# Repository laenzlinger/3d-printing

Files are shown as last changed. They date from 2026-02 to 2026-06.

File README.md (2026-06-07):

# 3d printing

Documentation for maintaining a Creality Ender 3 V2 Neo with Klipper firmware.

**Documentation:**
- [docs/maintenance.md](docs/maintenance.md) - System information and AI-assisted maintenance guide
- [docs/gitops.md](docs/gitops.md) - GitOps workflow for configuration management
- [docs/petg-guide.md](docs/petg-guide.md) - PETG printing guide and troubleshooting
- [docs/cura-petg-profile.md](docs/cura-petg-profile.md) - Cura profile setup for PETG
- [docs/session-notes.md](docs/session-notes.md) - Print session notes and tuning history

**Quick Commands:**
```bash
make              # Show all available commands
make status       # Check printer status
make sync         # Pull backup and verify
make deploy       # Deploy config to printer
make logs         # View Klipper logs
```

## OrcaSlicer Profiles

Profiles live in `orca-profiles/` and are used by the `make slice` command.

```bash
make profiles                                          # List available profiles
make slice STL=part.stl MATERIAL=PETG PROCESS="PETG Tuned"  # Slice with specific profile
make slice-print STL=part.stl MATERIAL=PETG PROCESS="PETG Strong"  # Slice and start print
```

### Filament Profiles

| Profile | Nozzle | Bed | Fan | Retraction | Use for |
|---|---|-----|-----|---|---|
| PLA | 200°C | 60°C | 40% | 1.5mm @ 30mm/s | General purpose, decorative parts |
| PETG | 235°C | 80°C | 40% | 1.5mm @ 30mm/s | Structural parts, outdoor use |

### Process Profiles

| Profile | Layers | Walls | Infill | Speed | Use for |
|---|---|---|---|---|---|
| PLA Tuned | 0.20mm | 3 (0.45mm) | 15% grid | 125mm/s | Fast PLA prints, non-structural |
| PETG Tuned | 0.20mm | 3 (0.4mm) | 25% gyroid | 50mm/s | Standard PETG, moderate strength |
| PETG Strong | 0.16mm | 4 (0.4mm) | 50% gyroid | 40mm/s | Max strength, functional/structural parts |

All process profiles share: 0.28mm first layer, 140% first layer line width (0.56mm), skirt by default (brim enabled case-by-case), 0.3mm Z-hop.

### Profile Selection Guide

- **Decorative / fast** → PLA + PLA Tuned
- **General PETG** → PETG + PETG Tuned
- **Structural / load-bearing** → PETG + PETG Strong (bike parts, brackets, mounts)

## Git Hooks

Run once after cloning:
```bash
./scripts/setup-git-hooks.sh
```

Pre-commit hooks check:
- Printer config syntax
- Cura profile structure
- No temp files committed

## TODO

- [ ] Extend start gcode purge line (current line is too short for consistent priming)
- [ ] Tune PETG retraction and feed settings (stringing/blob issues)
- [x] ~~Test PLA bed temp 65°C for better adhesion on textured PEI (ESP case warped at 60°C)~~
  - 65°C caused elephant foot, no warping improvement
  - Reducing PLA max fan to 40% fixed warping → applied to all PLA profiles

## Creality Ender 3 V2 Neo

### System Access

* Web Interface: https://3d.laenzlinger.net
* SSH: `ssh 3d.home`

### Mods

* [Filament guide](https://www.printables.com/model/93203-filament-guide-for-ender-3-v2)
* [Bed Leveling Wheel Clips](https://www.printables.com/model/115938-ender-3-bed-leveling-wheel-clips/files)
* [Camera Mount](https://www.printables.com/model/440579-ender-3-v2-neo-mount-for-pi-camera-module-v1-v2/files)
* [Light Bar](https://www.printables.com/model/360416-stealth-light-bar-resized-for-ender-3-pro-v2-neo-v)
* [Raspberry Pi Case](https://www.printables.com/model/106225-modular-snap-together-raspberry-pi-2b3b3b4-case-w-)

### Klipper Setup

The printer runs [Klipper](https://www.klipper3d.org/) firmware installed via [KIAUH](https://github.com/dw-0/kiauh).

Configuration backup is maintained at: https://github.com/laenzlinger/klipper-backup

Hardware:
* Creality 4.2.2 Mainboard
* TJC display

### Legacy Firmware (Pre-Klipper)

Previously used [Professional Firmware](https://github.com/mriscoc/Ender3V2S1) with [custom build for TJC display](https://github.com/mriscoc/Special_Configurations/releases/tag/tjc).

SD card formatting for firmware flashing (4096 byte sector size):

```sh
# Find the SD card
diskutil list

# Format as FAT32 with 4096 byte sector size (e.g., disk4s1)
sudo newfs_msdos -F 32 -b 4096 disk4s1
```

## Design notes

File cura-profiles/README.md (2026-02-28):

# Cura Profile Management

## Profile Structure

Cura 5.x uses two files per profile:
1. `creality_ender3_[NAME].inst.cfg` - Printer-level settings (bed temp, etc.)
2. `creality_base_extruder_0_[NAME].inst.cfg` - Extruder settings (temps, speeds, etc.)

## Installing Profiles

### Method 1: Copy to Cura config (Recommended)
```bash
cp cura-profiles/*.inst.cfg ~/.local/share/cura/5.11/quality_changes/
```

Then restart Cura and the profile will appear in your profiles list.

### Method 2: Import via Cura UI
Cura 5.x doesn't support importing `.inst.cfg` files directly through the UI.
Use Method 1 instead.

## Available Profiles

### PETG Profile
- **Files**: 
  - `creality_ender3_PETG.inst.cfg`
  - `creality_base_extruder_0_PETG.inst.cfg`
- **Settings**: Optimized for PETG at 240°C/80°C
- **Features**: Brim, Z-hop, proper cooling for PETG

### Modcase Profile (Your Current)
- **Files**:
  - `creality_ender3_modcase.inst.cfg`
  - `creality_base_extruder_0_%232_modcase.inst.cfg`
- **Settings**: 245°C, 100% infill, 5 walls

## Exporting Your Profiles

To backup your current profiles:
```bash
cp ~/.local/share/cura/5.11/quality_changes/*.inst.cfg ~/dev/gh/laenzlinger/3d-printing/cura-profiles/
```

## Start/End G-code

Update in: **Settings → Printer → Manage Printers → [Your Printer] → Machine Settings**

**Start G-code:**
```
START_PRINT BED_TEMP={material_bed_temperature_layer_0} EXTRUDER_TEMP={material_print_temperature_layer_0}
```

**End G-code:**
```
END_PRINT
```

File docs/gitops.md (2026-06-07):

# GitOps Workflow for Printer Configuration

## Overview

Configuration is managed through Git with automatic backups and manual deployments for safety.

**Repositories:**
- **Source of Truth**: https://github.com/laenzlinger/klipper-backup
- **Documentation**: https://github.com/laenzlinger/3d-printing

## Current Setup

### Automatic Backup (Pi → GitHub)

Klipper-Backup runs on the Pi and automatically commits/pushes changes to GitHub when:
- Configuration files are modified via Fluidd/Moonraker
- Manual trigger via Fluidd interface (Machine → Update Manager → klipper-backup)

**Backed up files:**
- `~/printer_data/config/*` (all config files)

**Excluded files:**
- Temporary files (*.swp, *.tmp, *.bak)
- Backup snapshots (printer-*.cfg)
- Data files (*.csv, *.zip)

**Configuration:** `~/klipper-backup/.env` on the Pi

### Manual Deployment (GitHub → Pi)

Changes made locally should be deployed manually to ensure safety.

## Workflow

### 1. Making Configuration Changes

#### Option A: Via Web Interface (Recommended for testing)
1. Edit config in Fluidd: https://3d.laenzlinger.net
2. Save and restart services
3. Test the changes
4. Backup is automatically pushed to GitHub
5. Pull changes locally: `cd ~/dev/gh/laenzlinger/klipper-backup && git pull`

#### Option B: Via Git (Recommended for planned changes)
1. Pull latest: `cd ~/dev/gh/laenzlinger/klipper-backup && git pull`
2. Edit config files locally
3. Commit and push to GitHub
4. Deploy to printer (see below)

### 2. Deploying Changes to Printer

```bash
# From your local machine
cd ~/dev/gh/laenzlinger/klipper-backup

# Review changes before deploying
git diff origin/main printer_data/config/printer.cfg

# Deploy to printer
scp printer_data/config/printer.cfg 3d.home:~/printer_data/config/

# Restart Klipper to apply changes
ssh 3d.home "sudo systemctl restart klipper"

# Or use Fluidd web interface: Firmware Restart
```

### 3. Verify Deployment

```bash
# Check service status
ssh 3d.home "systemctl status klipper"

# Check logs for errors
ssh 3d.home "tail -50 ~/printer_data/logs/klippy.log"
```

## Safety Practices

1. **Always test changes with a small test print first**
2. **Keep backup of working config before major changes**
3. **Review diffs before deploying**
4. **Monitor logs after deployment**
5. **Document significant changes in commit messages**

## Automation Scripts

### Deploy Script

Create `~/dev/gh/laenzlinger/klipper-backup/deploy.sh`:

```bash
#!/bin/bash
set -e

PRINTER="3d.home"
CONFIG_DIR="printer_data/config"

echo "Deploying configuration to printer..."

# Deploy all config files
rsync -av --exclude='*.bak' --exclude='*.bkp' \
  ${CONFIG_DIR}/ ${PRINTER}:~/${CONFIG_DIR}/

echo "Restarting Klipper..."
ssh ${PRINTER} "sudo systemctl restart klipper"

echo "Waiting for Klipper to start..."
sleep 3

echo "Checking status..."
ssh ${PRINTER} "systemctl status klipper --no-pager -l 0"

echo "Deployment complete!"
```

Make it executable:
```bash
chmod +x ~/dev/gh/laenzlinger/klipper-backup/deploy.sh
```

### Backup Verification Script

Create `~/dev/gh/laenzlinger/klipper-backup/verify-backup.sh`:

```bash
#!/bin/bash
set -e

PRINTER="3d.home"
CONFIG_DIR="printer_data/config"

echo "Comparing local backup with live config..."

# Fetch live config
ssh ${PRINTER} "cat ~/${CONFIG_DIR}/printer.cfg" > /tmp/live-printer.cfg

# Compare
if diff -q ${CONFIG_DIR}/printer.cfg /tmp/live-printer.cfg > /dev/null; then
  echo "✓ Backup is in sync with live config"
  exit 0
else
  echo "✗ Backup differs from live config:"
  diff -u ${CONFIG_DIR}/printer.cfg /tmp/live-printer.cfg
  exit 1
fi
```

Make it executable:
```bash
chmod +x ~/dev/gh/laenzlinger/klipper-backup/verify-backup.sh
```

## Troubleshooting

### Backup not pushing to GitHub

Check Moonraker logs:
```bash
ssh 3d.home "tail -100 ~/printer_data/logs/moonraker.log | grep -i backup"
```

Manually trigger backup:
```bash
ssh 3d.home "cd ~/klipper-backup && ./script.sh"
```

### Config changes not taking effect

1. Check for syntax errors in logs
2. Ensure Klipper restarted successfully
3. Try "Firmware Restart" in Fluidd (not just service restart)

### Merge conflicts

If both local and remote have changes:
```bash
cd ~/dev/gh/laenzlinger/klipper-backup
git fetch origin
git diff main origin/main  # Review differences
git pull --rebase  # Or manually merge
```

## Future Enhancements

Potential improvements to consider:

1. **Pre-deployment validation**: Syntax check before deploying
2. **Automated testing**: Test config in simulation before deploying
3. **Rollback mechanism**: Quick revert to last known good config
4. **Change notifications**: Alert on config changes
5. **CI/CD pipeline**: GitHub Actions for validation and deployment

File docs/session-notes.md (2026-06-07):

# Session Notes - PETG Calibration & MASS Project Setup

**Date:** 2026-02-28

## System Overview

**Printer:** Creality Ender 3 V2 Neo
- Klipper firmware via KIAUH
- Moonraker API on port 7125
- Fluidd web interface at https://3d.laenzlinger.net
- Crowsnest webcam configured
- BLTouch for bed leveling
- SSH access: `ssh 3d.home`

**Repository Structure:**
- `/home/laenzi/dev/gh/laenzlinger/3d-printing/` - Main repo (source of truth)
- `/home/laenzi/dev/gh/laenzlinger/mass-premium/` - NAS case project
- `/home/laenzi/dev/gh/laenzlinger/klipper-backup/` - Auto-backup (passive)

## Current Status

### PETG Calibration - COMPLETE ✅
- **Temperatures:** 240°C hotend / 80°C bed
- **Retraction:** 1.5mm @ 30mm/s with 0.3mm Z-hop
- **Cooling:** 40% fan (0% first layer)
- **Z-offset:** 1.985mm (adjusted -0.05mm from baseline 1.935mm)
- **Test cube:** 20mm cube printed successfully

### Bed Upgrade ✅
- **Old bed:** Magnetic bed was warped with 0.24mm variation (replaced 2026-04-06)
- **New bed:** Magnetic PEI bed (235x235mm) installed
- **TODO:** Run fresh bed mesh calibration (`make petg-bed-mesh`), verify Z-offset, test print

### Cura Profiles Created

**1. PETG (Basic)**
- 2 walls (0.8mm)
- 20% infill
- 0.2mm layers
- Use for: Test prints, small non-structural parts

**2. PETG Strong (Recommended for MASS project)**
- 3 walls (1.2mm)
- 25% gyroid infill
- 0.2mm layers
- 140% first layer line width (0.56mm)
- 8mm brim
- Use for: Structural parts, bay components

**3. PETG MASS (Alternative)**
- Similar to PETG Strong
- Had extrusion issues with 4 walls (too many retractions)
- Not recommended currently

### Key Settings That Work
- **Bed temp:** 80°C (NOT 70°C - this caused adhesion failures)
- **First layer line width:** 140% (critical for adhesion)
- **Retraction speed:** 30mm/s (quieter, prevents grinding)
- **Brim:** 8mm for large parts, optional for small parts
- **Speed:** 50mm/s print, 30mm/s outer wall, 60mm/s infill

### Issues Encountered & Solutions

**Problem:** Clips not sticking to bed
- **Cause:** Bed temp was 70°C instead of 80°C
- **Solution:** Fixed profile to use 80°C

**Problem:** Underextrusion with MASS profile
- **Cause:** 4 walls = too many retractions, filament grinding
- **Solution:** Reduced to 3 walls in PETG Strong profile

**Problem:** Retraction noise
- **Cause:** Retraction speed was 45mm/s
- **Solution:** Reduced to 30mm/s (matches test cube)

**Problem:** Second layer failures
- **Cause:** Warped bed creating uneven first layer
- **Solution:** Need new bed; workaround is positioning parts carefully

## MASS Premium NAS Case Project

**Goal:** 3D print case for 4x 3.5" HDDs

**Status:** Ready to print (new PEI bed installed 2026-04-06, needs calibration)

**Priority Parts (Bay Components):**
1. Clip x12 (test print) - 2-3 hours
2. BAYS_F (front bay) - ~37 hours with strong settings
3. BAYS_R (rear bay) - ~37 hours
4. HDD Slider x4 - ~2.5 hours each (can print 2 at once)
5. HDD Retainer x4 - ~2 hours each (can print all 4 at once)

**Files Location:**
- Original 3MF: `/home/laenzi/dev/gh/laenzlinger/mass-premium/*.3mf`
- Converted STL: `/home/laenzi/dev/gh/laenzlinger/mass-premium/stl/`
- Documentation: `BAY-PRIORITY-CHECKLIST.md`, `CURA-SETUP.md`

**Material Requirements:**
- BLACK PETG: ~1-1.5kg (structure, bays, small parts)
- GRAY PETG: ~1.5-2kg (exterior panels)
- TPU: ~50g (feet)

**Print Strategy:**
- Use PETG Strong profile
- Position parts on left/center of bed (avoid right edge)
- Start with small parts to verify settings
- Large parts (BAYS) take 30+ hours each

## Makefile Commands

```bash
make status          # Quick printer status
make monitor-simple  # Monitor print progress
make deploy          # Deploy config to printer
make sync-from-live  # Pull live config to source
make verify          # Compare source with live
make petg-bed-mesh   # Run bed mesh calibration at PETG temps
make petg-preheat    # Preheat for PETG
```

## Monitoring & Control

**Web Interface:** https://3d.laenzlinger.net
- Live webcam feed
- Temperature graphs
- Print progress
- G-code preview

**API Access:**
```bash
# Check status
ssh 3d.home 'curl -s "http://localhost:7125/printer/objects/query?print_stats"'

# Cancel print
ssh 3d.home 'curl -s -X POST http://localhost:7125/printer/print/cancel'

# Raise head
ssh 3d.home 'curl -s -X POST http://localhost:7125/printer/gcode/script -d "{\"script\":\"G91\\nG1 Z20 F600\\nG90\"}"'
```

## Next Steps (New PEI Bed Installed 2026-04-06)

1. ~~Install new magnetic PEI bed~~ ✅
2. **Run fresh bed mesh calibration:**
   ```bash
   make petg-bed-mesh
   ```
3. **Verify Z-offset with paper test**
4. **Test print:** Clip x12 with PETG Strong profile
5. **If successful:** Start bay components for MASS project

## Shopping List

**Critical:**
- [x] Magnetic PEI bed (235x235mm, textured or smooth) — installed 2026-04-06

**Optional:**
- [ ] Spare 0.4mm brass nozzles (pack of 5) - ~$10
- [ ] Digital calipers for measuring prints - ~$15-20
- [ ] BLACK PETG filament (1-2kg)
- [ ] GRAY PETG filament (1-2kg)

## Important Notes

- **Never use glue stick** - User preference, avoid in solutions
- **Bed mesh has 0.24mm variation** - This is significant, new bed is essential
- **Test cube worked perfectly** - Calibration is solid, bed is the issue
- **PETG Strong profile is proven** - Use this for all structural parts
- **Position parts carefully** - Avoid right edge of bed until new bed arrives
- **80°C bed temp is critical** - 70°C causes adhesion failures
- **3 walls is optimal** - 4 walls causes extrusion issues

## Files to Reference

- `PETG-GUIDE.md` - Complete PETG printing guide
- `CURA-SETUP.md` - Cura profile setup for MASS project
- `BAY-PRIORITY-CHECKLIST.md` - Print order for bay components
- `MAINTENANCE.md` - System maintenance guide
- `GITOPS.md` - Configuration management workflow

## Printer Configuration Files

- Source: `printer_data/config/printer.cfg`
- Live: `ssh 3d.home:~/printer_data/config/printer.cfg`
- Backup: `../klipper-backup/printer_data/config/printer.cfg`

## Lessons Learned

1. **Bed quality matters more than settings** - Can't compensate for 0.24mm warp
2. **First layer line width is critical** - 140% made huge difference
3. **Bed temperature must be correct** - 70°C vs 80°C = failure vs success
4. **Too many walls causes problems** - 4 walls = grinding, 3 walls = perfect
5. **Test small before large** - Clips revealed issues before committing to 37hr prints
6. **Position matters** - Using good area of bed is essential with warped bed
7. **Retraction speed affects noise** - 30mm/s is quieter than 45mm/s
8. **PETG needs higher temps than PLA** - 80°C bed minimum, not 70°C

## Success Criteria Met

✅ PETG temperatures calibrated (240°C/80°C)
✅ Retraction settings optimized (1.5mm @ 30mm/s)
✅ Test cube printed successfully
✅ Cura profiles created and tested
✅ MASS project files converted to STL
✅ Documentation complete
✅ Monitoring tools working
✅ GitOps workflow established

## Blockers

None currently — new PEI bed installed, ready for calibration and printing.

## When Resuming

1. Check if new bed has arrived
2. If yes: Install and calibrate
3. If no: Can print small parts (Clips, Retainers) in center of bed
4. Review `BAY-PRIORITY-CHECKLIST.md` for print order
5. Use PETG Strong profile for all structural parts
6. Monitor first layer closely on every print

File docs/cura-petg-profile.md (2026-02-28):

# Cura PETG Profile for Ender 3 V2 Neo

## Quick Settings

**Material:**
- Material: PETG
- Printing Temperature: 240°C
- Printing Temperature Initial Layer: 245°C
- Build Plate Temperature: 80°C
- Build Plate Temperature Initial Layer: 80°C

**Quality:**
- Layer Height: 0.2mm
- Initial Layer Height: 0.28mm
- Line Width: 0.4mm
- Wall Line Width: 0.4mm
- Initial Layer Line Width: 120% (0.48mm)

**Speed:**
- Print Speed: 50 mm/s
- Infill Speed: 60 mm/s
- Wall Speed: 40 mm/s
- Outer Wall Speed: 30 mm/s
- Initial Layer Speed: 20 mm/s
- Travel Speed: 150 mm/s

**Cooling:**
- Enable Print Cooling: Yes
- Fan Speed: 40%
- Regular Fan Speed at Height: 0.8mm (layer 4)
- Initial Fan Speed: 0%
- Regular Fan Speed at Layer: 4

**Retraction:**
- Enable Retraction: Yes
- Retraction Distance: 1.5mm
- Retraction Speed: 30 mm/s
- Z Hop When Retracted: Yes
- Z Hop Height: 0.3mm

**Build Plate Adhesion:**
- Build Plate Adhesion Type: Brim (recommended for PETG)
- Brim Width: 8mm
- Brim Line Count: 10

**Shell:**
- Wall Thickness: 1.2mm (3 walls)
- Top Layers: 5
- Bottom Layers: 5

**Infill:**
- Infill Density: 20%
- Infill Pattern: Grid or Gyroid

**Special Modes:**
- Print Sequence: All at Once

## Start G-code

```gcode
; Ender 3 V2 Neo PETG Start G-code
M140 S80                    ; Set bed temp
M104 S245                   ; Set hotend temp (first layer +5°C)
M190 S80                    ; Wait for bed temp
M109 S245                   ; Wait for hotend temp
G28                         ; Home all axes
BED_MESH_PROFILE LOAD=default ; Load bed mesh
G92 E0                      ; Reset extruder
G1 Z5 F3000                 ; Lift nozzle
G1 X10 Y10 F5000            ; Move to start position
G1 Z0.3 F3000               ; Lower to purge height
G1 X100 E15 F500            ; Purge line
G92 E0                      ; Reset extruder
G1 Z2 F3000                 ; Lift nozzle
M104 S240                   ; Set normal printing temp
```

## End G-code

```gcode
; Ender 3 V2 Neo PETG End G-code
G91                         ; Relative positioning
G1 E-2 F2700                ; Retract filament
G1 Z5 F3000                 ; Lift nozzle
G90                         ; Absolute positioning
G1 X0 Y220 F3000            ; Present print
M104 S0                     ; Turn off hotend
M140 S0                     ; Turn off bed
M106 S0                     ; Turn off fan
M84                         ; Disable motors
```

## Notes

- **Always use glue stick on the bed** - PETG bonds too strongly to bare surfaces
- Let the bed cool before removing prints (PETG releases easier when cool)
- First layer should be slightly less squished than PLA
- If you see stringing, increase retraction distance by 0.5mm increments
- If layers aren't adhering, increase temperature by 5°C

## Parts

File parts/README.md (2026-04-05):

# Custom 3D Parts

OpenSCAD source files for custom 3D printed parts.

## Workflow

1. Edit `.scad` files in this directory
2. Render to STL using OpenSCAD
3. Output files go to `../generated/`
4. Generated STL files are gitignored (build artifacts)

## Dependencies

- [BOSL2](https://github.com/BelfrySCAD/BOSL2) - Included as submodule for advanced OpenSCAD features

## Usage

```bash
# Render a part
openscad -o ../generated/part-name.stl part-name.scad

# Or use OpenSCAD GUI for interactive development
```

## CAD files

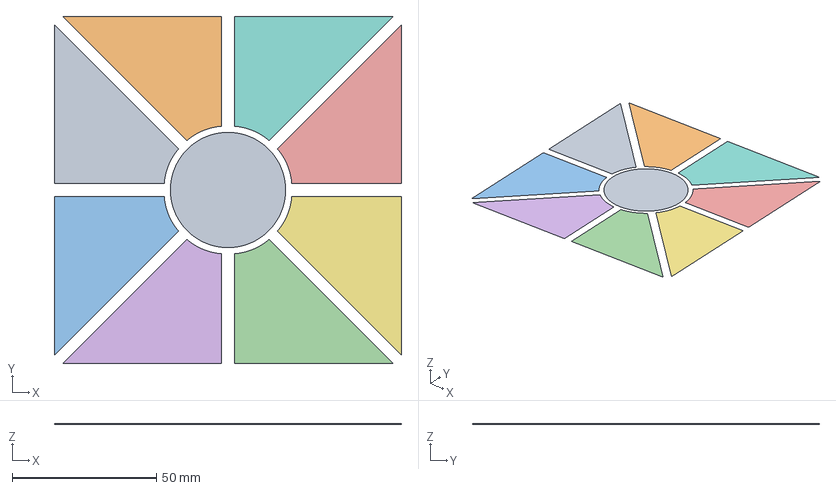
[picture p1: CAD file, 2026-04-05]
calibration/Macro_FirstLayer_Z-Offset_v1.4.3mf
120.5 x 120.5 x 0.2 mm
Center.stl
Tile_01.stl
Tile_02.stl
Tile_03.stl
Tile_04.stl
Tile_05.stl
Tile_06.stl
Tile_07.stl
Tile_08.stl

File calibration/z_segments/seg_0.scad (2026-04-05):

$fn = 64;
translate([100, 110, 0])
difference() {
    rotate([0, 0, 1])
        rotate_extrude(angle = 43)
            translate([20, 0]) square([30, 2]);
    
    translate([cos(22.5) * 35, sin(22.5) * 35, -0.1])
        rotate([0, 0, 22.5 - 90])
            linear_extrude(2.2)
                text("-100", size = 5, halign = "center", valign = "center");
}

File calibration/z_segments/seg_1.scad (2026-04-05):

$fn = 64;
translate([100, 110, 0])
difference() {
    rotate([0, 0, 46])
        rotate_extrude(angle = 43)
            translate([20, 0]) square([30, 2]);
    
    translate([cos(67.5) * 35, sin(67.5) * 35, -0.1])
        rotate([0, 0, 67.5 - 90])
            linear_extrude(2.2)
                text("-75", size = 5, halign = "center", valign = "center");
}

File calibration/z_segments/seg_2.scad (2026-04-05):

$fn = 64;
translate([100, 110, 0])
difference() {
    rotate([0, 0, 91])
        rotate_extrude(angle = 43)
            translate([20, 0]) square([30, 2]);
    
    translate([cos(112.5) * 35, sin(112.5) * 35, -0.1])
        rotate([0, 0, 112.5 - 90])
            linear_extrude(2.2)
                text("-50", size = 5, halign = "center", valign = "center");
}

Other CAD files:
calibration/z_segments/seg_3.scad
calibration/z_segments/seg_4.scad
calibration/z_segments/seg_5.scad
calibration/z_segments/seg_6.scad
calibration/z_segments/seg_7.scad
models/dinrailmount-pcb-32x72.scad
models/dinrailmountmulti.scad
models/washer-m3-3mm.scad
parts/betthaj-label.scad
parts/dust-collector-adapter.scad
parts/endstop-adapter.scad
parts/metric_drill_bit_holder.scad
parts/microscope-adapter.scad
parts/shower-adapter.scad

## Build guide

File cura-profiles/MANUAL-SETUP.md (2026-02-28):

# Cura PETG Settings - Manual Setup

Copy these settings into Cura manually:

## Material Settings
- **Printing Temperature**: 240°C
- **Build Plate Temperature**: 80°C

## Quality
- **Layer Height**: 0.2mm
- **Initial Layer Height**: 0.28mm
- **Line Width**: 0.4mm
- **Initial Layer Line Width**: 120% (0.48mm)

## Shell
- **Wall Thickness**: 1.2mm (3 walls)
- **Top Layers**: 5
- **Bottom Layers**: 5

## Infill
- **Infill Density**: 20%
- **Infill Pattern**: Grid

## Speed
- **Print Speed**: 50 mm/s
- **Infill Speed**: 60 mm/s
- **Wall Speed**: 40 mm/s
- **Outer Wall Speed**: 30 mm/s
- **Initial Layer Speed**: 20 mm/s
- **Travel Speed**: 150 mm/s

## Cooling
- **Enable Print Cooling**: Yes
- **Fan Speed**: 40%
- **Initial Fan Speed**: 0%
- **Regular Fan Speed at Height**: 0.8mm

## Travel
- **Enable Retraction**: Yes
- **Retraction Distance**: 1.5mm
- **Retraction Speed**: 30 mm/s
- **Z Hop When Retracted**: Yes
- **Z Hop Height**: 0.3mm

## Build Plate Adhesion
- **Build Plate Adhesion Type**: Brim
- **Brim Width**: 8mm

## Start/End G-code

**In Cura: Settings → Printer → Manage Printers → [Your Printer] → Machine Settings**

**Start G-code:**
```
START_PRINT BED_TEMP={material_bed_temperature_layer_0} EXTRUDER_TEMP={material_print_temperature_layer_0}
```

**End G-code:**
```
END_PRINT
```

## Quick Setup
1. Select your Ender 3 printer in Cura
2. Create a new profile: **Preferences → Profiles → Create**
3. Name it "PETG"
4. Apply all the settings above
5. Update the start/end G-code in Machine Settings

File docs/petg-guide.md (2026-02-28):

# PETG Printing Guide - Ender 3 V2 Neo

## PETG Characteristics

PETG is more challenging than PLA but offers better strength, flexibility, and temperature resistance.

**Key differences from PLA:**
- More stringing (needs retraction tuning)
- Sticks aggressively to bed (can damage surface)
- More sensitive to speed and temperature
- Requires more cooling control
- Hygroscopic (absorbs moisture)

## Recommended Settings

### Temperatures
- **Nozzle**: 230-250°C (start at 240°C)
- **Bed**: 70-85°C (start at 80°C)
- **First layer nozzle**: +5°C (245°C if printing at 240°C)

### Speeds
- **Print speed**: 40-60 mm/s (start at 50 mm/s)
- **First layer**: 20-30 mm/s
- **Outer walls**: 30-40 mm/s
- **Infill**: 50-60 mm/s
- **Travel speed**: 150 mm/s

### Cooling
- **First layer**: 0% fan
- **Layers 2-3**: 0-20% fan
- **Layer 4+**: 30-50% fan (PETG needs less cooling than PLA)

### Retraction (Direct Drive)
- **Distance**: 1-2mm (start at 1.5mm)
- **Speed**: 25-35 mm/s (start at 30 mm/s)
- **Z-hop**: 0.2-0.4mm (helps with stringing)

### First Layer
- **Height**: 0.2-0.28mm (thicker is better for PETG)
- **Line width**: 120% of nozzle (0.48mm for 0.4mm nozzle)
- **Speed**: 20 mm/s
- **Bed temp**: 80-85°C

### Other Settings
- **Layer height**: 0.12-0.28mm (0.2mm is good balance)
- **Line width**: 0.4-0.48mm
- **Flow rate**: 95-100% (start at 100%, reduce if over-extruding)

## Bed Adhesion

**Critical for PETG:**
1. Clean bed with IPA (isopropyl alcohol)
2. Use glue stick or painter's tape (prevents PETG bonding too strongly)
3. Let bed cool before removing print (PETG releases easier when cool)
4. Never use bare glass - PETG can fuse to it permanently

## Pre-Print Checklist

### 1. Dry Your Filament
PETG absorbs moisture quickly. Signs of wet filament:
- Popping/hissing sounds during printing
- Excessive stringing
- Rough surface finish
- Weak layer adhesion

**Drying**: 65°C for 4-6 hours in food dehydrator or filament dryer

### 2. Calibrate for PETG

Run these calibrations in order:

#### A. PID Tuning (Essential)
```gcode
# Hotend PID tune at 240°C
PID_CALIBRATE HEATER=extruder TARGET=240

# Bed PID tune at 80°C  
PID_CALIBRATE HEATER=heater_bed TARGET=80

# Save results
SAVE_CONFIG
```

#### B. First Layer Calibration
```gcode
# Heat up
M104 S240  ; Set hotend temp
M140 S80   ; Set bed temp
M109 S240  ; Wait for hotend
M190 S80   ; Wait for bed

# Run bed mesh
G28        ; Home
BED_MESH_CALIBRATE

# Print first layer test
# Adjust Z offset until first layer is slightly squished but not too flat
```

#### C. Temperature Tower
Print a temperature tower (230-250°C) to find optimal temperature:
- Look for best layer adhesion
- Minimal stringing
- Clean overhangs
- Smooth surface

#### D. Retraction Test
Print retraction test to tune:
- Retraction distance (1-2mm)
- Retraction speed (25-35 mm/s)
- Z-hop (0.2-0.4mm)

#### E. Flow Rate Calibration
Print single-wall cube and measure wall thickness:
- Target: 0.4mm for 0.4mm nozzle
- Adjust flow rate: `new_flow = (target_width / measured_width) * current_flow`

## Klipper Configuration Additions

Add these to your printer.cfg for PETG printing:

```ini
# PETG Pressure Advance (tune this)
# Start with 0.05, adjust based on corners
[extruder]
pressure_advance: 0.05
pressure_advance_smooth_time: 0.040

# PETG Macros
[gcode_macro PETG_PREHEAT]
gcode:
    M140 S80          ; Set bed temp
    M104 S240         ; Set hotend temp
    M190 S80          ; Wait for bed
    M109 S240         ; Wait for hotend

[gcode_macro PETG_START]
gcode:
    G28                           ; Home
    BED_MESH_CALIBRATE           ; Create bed mesh
    G1 Z5 F3000                  ; Lift nozzle
    M140 S80                     ; Set bed temp
    M104 S245                    ; Set first layer temp (+5°C)
    M190 S80                     ; Wait for bed
    M109 S245                    ; Wait for hotend
    G92 E0                       ; Reset extruder
    G1 Z0.3 F3000                ; Lower nozzle
    G1 X10 Y10 F5000             ; Move to start
    G1 X100 E15 F500             ; Purge line
    G92 E0                       ; Reset extruder
    M104 S240                    ; Set normal temp

[gcode_macro PETG_END]
gcode:
    G91                          ; Relative positioning
    G1 E-2 F2700                 ; Retract
    G1 Z5 F3000                  ; Lift nozzle
    G90                          ; Absolute positioning
    G1 X0 Y220 F3000             ; Present print
    M104 S0                      ; Turn off hotend
    M140 S0                      ; Turn off bed
    M106 S0                      ; Turn off fan
    M84                          ; Disable motors
```

## Troubleshooting

### Stringing
- Increase retraction distance (0.5mm increments)
- Increase retraction speed
- Enable Z-hop (0.2-0.3mm)
- Lower temperature (5°C increments)
- Increase travel speed

### Poor Layer Adhesion
- Increase temperature (5°C increments)
- Reduce cooling fan speed
- Slow down print speed
- Check filament is dry

### Warping
- Increase bed temperature
- Use enclosure or draft shield
- Reduce cooling fan
- Add brim or raft

### Oozing/Blobbing
- Lower temperature
- Increase retraction
- Enable "wipe while retracting"
- Reduce "extra restart distance"

### First Layer Not Sticking
- Increase bed temperature to 85°C
- Lower Z offset (squish more)
- Clean bed thoroughly
- Apply glue stick
- Slow down first layer (15-20 mm/s)

### First Layer Too Sticky (Can't Remove Print)
- Let bed cool completely (below 40°C)
- Use glue stick or painter's tape as release agent
- Reduce bed temperature to 75°C

## Slicer Profile (PrusaSlicer/OrcaSlicer)

```
Filament: PETG
Nozzle: 240°C (first layer 245°C)
Bed: 80°C
Layer height: 0.2mm
First layer height: 0.28mm
Line width: 0.4mm (first layer 0.48mm)

Speeds:
- Perimeters: 40 mm/s
- External perimeters: 30 mm/s
- Infill: 60 mm/s
- First layer: 20 mm/s
- Travel: 150 mm/s

Cooling:
- Min fan speed: 30%
- Max fan speed: 50%
- Disable fan first layer: Yes
- Enable fan if layer time < 15s

Retraction:
- Length: 1.5mm
- Speed: 30 mm/s
- Z-hop: 0.3mm
- Wipe while retracting: Yes

Extrusion:
- Extrusion multiplier: 1.0 (adjust after calibration)
```

## Testing Workflow

1. **Dry filament** (if not fresh from sealed bag)
2. **PID tune** hotend and bed
3. **Bed mesh calibration**
4. **First layer test** - adjust Z offset
5. **Temperature tower** - find optimal temp
6. **Retraction test** - minimize stringing
7. **Small test print** - verify all settings
8. **Large project** - monitor first few layers closely

## Storage

- Store PETG in airtight container with desiccant
- Re-dry before use if stored for >2 weeks
- Keep away from humidity

## Safety Notes

- PETG can emit fumes - ensure good ventilation
- Bed can be very sticky - use tools to remove prints, not fingers
- Let prints cool before removal to avoid warping

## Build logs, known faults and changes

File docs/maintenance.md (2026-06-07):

# Maintenance Guide

## System Overview

**Hardware:**
- Creality Ender 3 V2 Neo
- Creality 4.2.2 Mainboard
- TJC display
- Raspberry Pi with camera module

**Software Stack:**
- Klipper firmware (installed via KIAUH)
- Moonraker (API server)
- Fluidd (web interface)
- Crowsnest (camera streaming)

**Access:**
- Web: https://3d.laenzlinger.net
- SSH: `ssh 3d.home`
- Local IP: 192.168.1.142

## Configuration Locations

### On Raspberry Pi
- Main config: `~/printer_data/config/printer.cfg`
- Moonraker: `~/printer_data/config/moonraker.conf`
- Camera: `~/printer_data/config/crowsnest.conf`
- Fluidd: `~/printer_data/config/fluidd.cfg` (symlink to `~/fluidd-config/fluidd.cfg`)
- Logs: `~/printer_data/logs/`

### Backup Repository
- GitHub: https://github.com/laenzlinger/klipper-backup
- Local clone: `../klipper-backup/printer_data/config/`
- Auto-backup via Klipper-Backup script

## Common Maintenance Tasks

### Check System Status
```bash
ssh 3d.home "systemctl status klipper moonraker crowsnest"
```

### View Logs
```bash
ssh 3d.home "tail -f ~/printer_data/logs/klippy.log"
ssh 3d.home "tail -f ~/printer_data/logs/moonraker.log"
```

### Restart Services
```bash
ssh 3d.home "sudo systemctl restart klipper"
ssh 3d.home "sudo systemctl restart moonraker"
ssh 3d.home "sudo systemctl restart crowsnest"
```

### Update Klipper/Moonraker
Use KIAUH on the Pi:
```bash
ssh 3d.home
cd ~/kiauh
./kiauh.sh
# Select option 1 (Update)
```

### Backup Configuration
Configuration is automatically backed up to GitHub via the Klipper-Backup script.
Manual backup:
```bash
ssh 3d.home "cd ~/klipper-backup && git pull && git add . && git commit -m 'Manual backup' && git push"
```

## AI-Assisted Maintenance

### What AI Can Help With

1. **System Health Checks**
   - Ask AI to SSH in and check service status
   - Review logs for errors
   - Monitor disk space and system resources

2. **Configuration Changes**
   - Review and modify printer.cfg
   - Adjust print settings
   - Configure new features

3. **Troubleshooting**
   - Analyze error messages from logs
   - Debug connection issues
   - Investigate print quality problems

4. **Documentation Updates**
   - Keep README and this file current
   - Document new mods or changes
   - Track firmware versions

### Example AI Prompts

- "Check the 3D printer system status via SSH"
- "Review the latest Klipper logs for errors"
- "Compare the current printer.cfg with the backup"
- "Update the README with the new camera settings"
- "Help me troubleshoot why prints are failing at layer 10"

### Important Notes

- Always review AI-suggested configuration changes before applying
- Test configuration changes with a small test print first
- Keep backups before major changes
- The klipper-backup repo is the source of truth for configs

## Known Issues

### OctoApp Subscription Failures
Moonraker logs show repeated "octoapp" subscription failures (HTTP 404). This is non-critical - it's just a notification service that's not configured. Can be ignored or disabled in moonraker.conf if desired.

## Service Ports

- Fluidd web interface: 80/443 (via reverse proxy)
- Moonraker API: 7125
- Camera stream: 8080 (localhost only)

## Useful Commands

### Check camera
```bash
ssh 3d.home "v4l2-ctl --list-devices"
```

### View system resources
```bash
ssh 3d.home "htop"
```

### Check network
```bash
ssh 3d.home "ip addr show"
```

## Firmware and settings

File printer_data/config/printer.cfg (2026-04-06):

# This file contains pin mappings for the stock 2022 Creality Ender 3
# V2 Neo. To use this config, during "make menuconfig" select the
# STM32F103 with a "28KiB bootloader" and serial (on USART1 PA10/PA9)
# communication.

# If you prefer a direct serial connection, in "make menuconfig"
# select "Enable extra low-level configuration options" and select
# serial (on USART3 PB11/PB10), which is broken out on the 10 pin IDC
# cable used for the LCD module as follows:
# 3: Tx, 4: Rx, 9: GND, 10: VCC

# Flash this firmware by copying "out/klipper.bin" to a SD card and
# turning on the printer with the card inserted. The firmware
# filename must end in ".bin" and must not match the last filename
# that was flashed.

# This also works for the GD32F303 based Creality 4.2.2 board.

# See docs/Config_Reference.md for a description of parameters.

[stepper_x]
step_pin: PC2
dir_pin: PB9
enable_pin: !PC3
microsteps: 16
rotation_distance: 40
endstop_pin: ^PA5
position_endstop: -15
position_min: -55
position_max: 220
homing_speed: 80

[stepper_y]
step_pin: PB8
dir_pin: PB7
enable_pin: !PC3
microsteps: 16
rotation_distance: 40
endstop_pin: ^PA6
position_endstop: 0
position_max: 220
homing_speed: 80

[stepper_z]
step_pin: PB6
dir_pin: !PB5
enable_pin: !PC3
microsteps: 16
rotation_distance: 8
endstop_pin: probe:z_virtual_endstop
position_max: 250
position_min: -5
homing_speed: 4
second_homing_speed: 1
homing_retract_dist: 2.0

[extruder]
max_extrude_only_distance: 100.0
step_pin: PB4
dir_pin: PB3
enable_pin: !PC3
microsteps: 16
rotation_distance: 7.618
nozzle_diameter: 0.400
filament_diameter: 1.750
heater_pin: PA1
sensor_type: EPCOS 100K B57560G104F
sensor_pin: PC5
# pressure_advance: 0.05
#control: pid
# tuned for stock hardware with 200 degree Celsius target
#pid_Kp: 21.527
#pid_Ki: 1.063
#pid_Kd: 108.982
min_temp: 0
max_temp: 250

[verify_heater extruder]
max_error: 120
check_gain_time: 60
hysteresis: 10
heating_gain: 1

[heater_bed]
heater_pin: PA2
sensor_type: EPCOS 100K B57560G104F
sensor_pin: PC4
#control: pid
# tuned for stock hardware with 70 degree Celsius target
#pid_kp: 70.405
#pid_ki: 1.229
#pid_kd: 1008.553
min_temp: 0
max_temp: 130

[fan]
pin: PA0

[mcu]
serial: /dev/serial/by-id/usb-1a86_USB_Serial-if00-port0
restart_method: command

[printer]
kinematics: cartesian
max_velocity: 300
max_accel: 5000
max_z_velocity: 5
square_corner_velocity: 5.0
max_z_accel: 100

[bltouch]
sensor_pin: ^PB1
control_pin: PB0
x_offset: -40.0
y_offset: -15.0
#z_offset: 0
speed: 20
samples: 2
samples_tolerance: 0.05
samples_tolerance_retries: 3
sample_retract_dist: 5.0

[safe_z_home]
home_xy_position: 140,125
speed: 150
z_hop: 10
z_hop_speed: 10

[bed_mesh]
speed: 120
mesh_min: 40,15         # Maximum probeable area with BLTouch offset
mesh_max: 180,205       # Maximum probeable area with BLTouch offset
probe_count: 7,7
fade_start: 1
fade_end: 10
fade_target: 0
algorithm: bicubic

[bed_screws]
screw1:30,25
screw1_name:1
screw2:200,25
screw2_name:2
screw3:200,195
screw3_name:3
screw4:30,195
screw4_name:4

[screws_tilt_adjust]
screw1: 55, 40
screw1_name: front left screw
screw2: 220, 40
screw2_name: front right screw
screw3: 220, 210
screw3_name: rear right screw
screw4: 55, 210
screw4_name: rear left screw
horizontal_move_z: 10
speed: 200
screw_thread: CCW-M4

# [display]
# The Ender 3 v2 Neo's 4.3" LCD display is not supported by klipper

[output_pin beeper]
pin: PB13

[filament_switch_sensor filament_sensor]
pause_on_runout: True
switch_pin: PA4

[virtual_sdcard]
path: ~/printer_data/gcodes

[display_status]


[gcode_macro START_PRINT]
gcode:
    {% set BED_TEMP = params.BED_TEMP|default(60)|float %}
    {% set EXTRUDER_TEMP = params.EXTRUDER_TEMP|default(210)|float %}
    # Start heating
    M140 S{BED_TEMP}
    M104 S{EXTRUDER_TEMP}
    # Use absolute coordinates
    G90
    # Home the printer
    G28
    # Load material-specific bed mesh and Z offset
    # Base z_offset is tuned for PLA; PETG needs -0.05mm more squish
    {% if BED_TEMP >= 75 %}
        BED_MESH_PROFILE LOAD=petg
        SET_GCODE_OFFSET Z_ADJUST=-0.05 MOVE=1
    {% else %}
        BED_MESH_PROFILE LOAD=pla
    {% endif %}
    # Wait for bed to reach temperature
    M190 S{BED_TEMP}
    # Wait for nozzle to reach temperature
    M109 S{EXTRUDER_TEMP}
    # Reset extruder
    G92 E0
    # Move to start position
    G1 Z5 F3000
    G1 X2 Y20 F5000
    G1 Z0.3 F3000
    # Purge line (two lines along Y axis, slow for adhesion)
    G1 Y100 E10 F600
    G1 Y200 E20 F1000
    G1 X2.4 F5000
    G1 Y20 E40 F1000
    G92 E0
    G1 Z2 F3000


[gcode_macro END_PRINT]
gcode:
    # Turn off bed, extruder, and fan
    M140 S0
    M104 S0
    M106 S0
    # Move nozzle away from print while retracting
    G91
    G1 E-2 F2700
    G1 Z5 F3000
    G90
    # Present print
    G1 X0 Y220 F3000
    # Disable steppers
    M84

[gcode_macro PAUSE]
description: Pause the actual running print
rename_existing: PAUSE_BASE
# change this if you need more or less extrusion
variable_extrude: 1.0
gcode:
  ##### read E from pause macro #####
  {% set E = printer["gcode_macro PAUSE"].extrude|float %}
  ##### set park positon for x and y #####
  # default is your max posion from your printer.cfg
  {% set x_park = printer.toolhead.axis_maximum.x|float - 5.0 %}
  {% set y_park = printer.toolhead.axis_maximum.y|float - 5.0 %}
  ##### calculate save lift position #####
  {% set max_z = printer.toolhead.axis_maximum.z|float %}
  {% set act_z = printer.toolhead.position.z|float %}
  {% if act_z < (max_z - 2.0) %}
      {% set z_safe = 2.0 %}
  {% else %}
      {% set z_safe = max_z - act_z %}
  {% endif %}
  ##### end of definitions #####
  PAUSE_BASE
  G91
  {% if printer.extruder.can_extrude|lower == 'true' %}
    G1 E-{E} F2100
  {% else %}
    {action_respond_info("Extruder not hot enough")}
  {% endif %}
  {% if "xyz" in printer.toolhead.homed_axes %}
    G1 Z{z_safe} F900
    G90
    G1 X{x_park} Y{y_park} F6000
  {% else %}
    {action_respond_info("Printer not homed")}
  {% endif %} 

[gcode_macro RESUME]
description: Resume the actual running print
rename_existing: RESUME_BASE
gcode:
  ##### read E from pause macro #####
  {% set E = printer["gcode_macro PAUSE"].extrude|float %}
  #### get VELOCITY parameter if specified ####
  {% if 'VELOCITY' in params|upper %}
    {% set get_params = ('VELOCITY=' + params.VELOCITY)  %}
  {%else %}
    {% set get_params = "" %}
  {% endif %}
  ##### end of definitions #####
  {% if printer.extruder.can_extrude|lower == 'true' %}
    G91
    G1 E{E} F2100
  {% else %}
    {action_respond_info("Extruder not hot enough")}
  {% endif %}  
  RESUME_BASE {get_params}

[gcode_macro CANCEL_PRINT]
description: Cancel the actual running print
rename_existing: CANCEL_PRINT_BASE
gcode:
  TURN_OFF_HEATERS
  G91
  G1 Z20 F600
  G90
  G1 X0 Y220 F3000
  CANCEL_PRINT_BASE


[gcode_macro M75]
gcode:
 

######################################################################
# Filament Change
######################################################################

# M600: Filament Change. This macro will pause the printer, move the
# tool to the change position, and retract the filament 50mm. Adjust
# the retraction settings for your own extruder. After filament has
# been changed, the print can be resumed from its previous position
# with the "RESUME" gcode.

[pause_resume]

[gcode_macro M600]
gcode:
    {% set X = params.X|default(50)|float %}
    {% set Y = params.Y|default(0)|float %}
    {% set Z = params.Z|default(10)|float %}
    SAVE_GCODE_STATE NAME=M600_state
    PAUSE
    G91
    G1 E-.8 F2700
    G1 Z{Z}
    G90
    G1 X{X} Y{Y} F3000
    G91
    G1 E-50 F1000
    RESTORE_GCODE_STATE NAME=M600_state
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

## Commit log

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2023-08-02 Watch the bed leveling in plugin and wait for bed to be heated before auto-levelling
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2023-08-04 Fix bed visualiser reporting
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2024-12-07 Add microscpe-adapter
    [microscope-adapter.scad]
2024-12-07 Add generated files
    [microscope-adapter.stl]
2024-12-07 More stable desing of microscope adapter
    [microscope-adapter.scad]
2024-12-07 Fix screw hole
    [microscope-adapter.scad, microscope-adapter.stl]
2024-12-08 Make it smaller again
    [microscope-adapter.scad, microscope-adapter.stl]
2025-06-23 Add shower adapter
    [shower-adapter.scad]
2025-07-18 Latest changes
    [shower-adapter.scad]
2025-07-18 Add parametric dust collector adapter
    [dust-collector-adapter.scad]
2025-07-29 Add original drill bit holdre
    [metric_drill_bit_holder.scad]
2025-07-29 Rotate the holes and use max shaft size
    [metric_drill_bit_holder.scad]
2025-07-29 Add module
    [metric_drill_bit_holder.scad]
2025-07-31 Increase number of rows
    [metric_drill_bit_holder.scad]
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2025-08-10 Add klipper printer.cfg to backup
    [printer.cfg]
2025-08-13 change plugins for klipper
    [printer.cfg]
2025-08-19 Add endstop adapter
    [endstop-adapter.scad]
2025-08-19 Bad mesh and z offset changes
    [printer.cfg]
2025-08-19 move pritner config
    [printer.cfg]
2025-08-19 Add filament runout sensor config
    [printer.cfg]
2026-01-17 latest backup
    [printer.cfg]
2026-01-18 Revert "latest backup"
    This reverts commit 761254361f0f8bbd0104b22206d219ec630652cc.
    [printer.cfg]
2026-01-18 backup from new octopi system
    [printer.cfg]
2026-02-07 Betthaj Label
    [betthaj-label.scad]
2026-02-08 Use better font
    [betthaj-label.scad]
2026-02-08 dynamic scaling of the angles
    [betthaj-label.scad]
2026-02-28 PETG calibration complete and MASS project setup
    - Completed PETG calibration (240°C/80°C, test cube successful)
    - Created PETG MASS Structural Cura profile for NAS case project
    - Added monitoring scripts (Python-based with simple fallback)
    - Converted MASS bay components from 3mf to STL for Cura compatibility
    - Updated documentation (PETG-GUIDE.md, CURA-PETG-PROFILE.md)
    - Cleaned up legacy octoprint and ender3.v2.neo directories
    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
    [betthaj-label.scad, printer.cfg]
2026-02-28 Finalize PETG Strong profile for MASS project
    - Created PETG Strong profile (3 walls, 25% gyroid infill)
    - Optimized for structural parts without extrusion issues
    - Fixed bed temperature to 80°C (was incorrectly 70°C)
    - Increased first layer line width to 140% for better adhesion
    - Adjusted retraction speed to 30mm/s (quieter, matches test cube)
    - Updated MASS profile settings based on printing tests
    - Z-offset adjusted to -0.05mm from baseline for better adhesion
    Note: Bed mesh shows 0.24mm variation - new magnetic PEI bed recommended
2026-02-28 Update printer config with adjusted Z-offset
    Z-offset lowered by 0.05mm total for better PETG adhesion
    (from 1.935mm baseline)
    [printer.cfg]
2026-02-28 Add comprehensive session notes for future reference
    Documents:
    - Complete PETG calibration results
    - Bed mesh issues and workarounds
    - Cura profile details and rationale
    - MASS project status and next steps
    - All issues encountered and solutions
    - Commands and workflows
    - Shopping list for new bed
    - Lessons learned
2026-02-28 Add pre-commit hooks for config validation
    - Check printer.cfg syntax before commit
    - Validate Cura profile structure
    - Prevent temp files from being committed
    - Add setup script for easy installation
    - Document in README
2026-03-10 PETG calibration, extended purge line, deploy safety check
    - Sync printer.cfg with latest calibration (PID, z_offset, 7x7 bed mesh)
    - Extend start gcode purge line (two 180mm lines along Y axis)
    - Add pre-deploy calibration check with merge option (make deploy)
    - Add TODOs for purge line and PETG retraction tuning
    [printer.cfg]
2026-03-16 Updated a lot of octoprint stuff
    [printer.cfg]
2026-04-05 Add new docs
    [printer.cfg]
2026-04-05 Add PLA Tuned Cura profile
    Based on Multiboard Default with anti-warp tuning:
    - Bed temp: 60°C
    - First layer speed: 25mm/s
    - First layer line width: 140%
    - Print speed: 125mm/s
    - 3 walls, 15% infill
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2026-04-05 Auto-adjust Z offset per material in START_PRINT macro
    PETG (bed >= 75°C) gets -0.05mm Z adjustment for more squish.
    PLA uses base z_offset as-is.
    No manual changes needed when switching materials.
    [printer.cfg]
2026-04-05 Use direct IP for printer SSH access
    3d.laenzlinger.net is now a reverse proxy, SSH requires direct IP.
2026-04-05 Add Cura machine instance to version control
    Renamed to 'Ender 3 V2 Neo (Klipper)'.
    Fixed active profile reference (was pointing to deleted Multiboard Default).
    [Creality+Ender-3+%2F+Ender-3+v2.global.cfg]
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2026-04-05 Replace generic filament profiles with actual filament inventory
    - Elegoo PLA (Beige, Wood)
    - Creality PLA Matte (multiple colors)
    - SUNLU PLA Matte (Olive Green)
    - Creality PETG (multiple colors)
2026-04-05 Fix OrcaSlicer filament bed temps for all plate types
    Set all plate types (cool/hot/textured/eng) to correct temps.
    Without this, OrcaSlicer defaults to cool_plate_temp (35°C for PLA).
2026-04-05 Add CLI slicing workflow
    Scripts:
    make slice STL=file.stl - Slice with defaults (PLA Matte)
    make slice-upload STL=file.stl - Slice and upload to printer
    make slice-print STL=file.stl - Slice, upload and start printing
    make profiles - List available profiles
    Custom material/process:
    make slice STL=file.stl MATERIAL='Creality PETG' PROCESS='PETG Tuned'
    Fixed OrcaSlicer profiles for CLI compatibility.
2026-04-05 Recalibrate bed: fix BLTouch offset, level screws, new bed mesh
    - BLTouch offset corrected to X:-40 Y:-15
    - Screw positions updated for 170x170 centered pattern
    - Bed leveled via SCREWS_TILT_CALCULATE (all within 00:12)
    - New bed mesh: 0.24mm variation (was 0.62mm)
    [printer.cfg]
2026-04-05 New bed mesh after cleaning: 0.15mm variation
    [printer.cfg]
2026-04-05 Recalibrate Z-offset for new bed: 1.961mm
    [printer.cfg]
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2026-04-05 Replace brim with 3-loop skirt (5mm gap) for PLA Tuned
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2026-04-05 Reduce PLA fan speed to 50-70% (was 100%)
    100% fan caused all-around warping due to excessive cooling.
2026-04-05 Lower Z-offset to 1.911 for better first layer squish
    [printer.cfg]
2026-04-05 Z-offset 1.861, position_min -3 for new textured bed
    [printer.cfg]
2026-04-05 Z-offset 1.836 after live tuning
    [printer.cfg]
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2026-04-05 Revert first layer flow to 100% - tune Z-offset instead
2026-04-05 WIP: wider line widths to fix first layer gaps
    - line_width: 0.56mm, solid infill: 0.56mm, outer wall: 0.5mm
    - z_offset: 1.836
    - Still investigating first layer gap issue (OrcaSlicer bottom surface spacing)
    [betthaj-label.scad]
2026-04-05 Z-offset 2.136 - correct value after manual paper test
    Previous PROBE_CALIBRATE gave 1.961 which was ~0.45mm too low.
    Manual test: Z=0 had no contact, paper friction at Z=-0.45.
    [printer.cfg]
2026-04-05 Clean up PLA profile after Z-offset fix
    Z-offset was the root cause (2.086). Reverted compensating hacks:
    - Line widths back to normal for upper layers (0.42-0.45mm)
    - First layer stays wide (0.56mm, 0.3mm height)
    - Removed gap fill and overlap overrides
    - Kept: accelerations, rectilinear bottom, skirt
    [printer.cfg]
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2026-04-05 Add 8-in-1 Z-offset first layer calibration model
    Source: https://www.printables.com/model/841325
    [Macro_FirstLayer_Z-Offset_v1.4.3mf]
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2026-04-05 Z-offset 2.061 confirmed good first layer
    [printer.cfg]
2026-04-05 Add repeatable Z-offset calibration: make z-calibrate
    8 pie segments with offset labels (-100 to +75 microns).
    Auto-cancels after first layer. Pick best segment to adjust.
    [seg_0.scad, seg_1.scad, seg_2.scad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]
2026-04-05 Raise head and present bed on CANCEL_PRINT
    [printer.cfg]
2026-04-05 Z-offset 2.036 - tuned via 8-segment calibration print
    [printer.cfg]
2026-04-05 Finalize z-calibrate: make z-calibrate
    Center circle (current offset) + 8 segments (-100 to +100 microns)
    with offset values as cutout labels. Auto-cancels after first layer.
    Pick best segment, adjust z_offset accordingly.
    [seg_0.scad, seg_1.scad, seg_2.scad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]
2026-04-06 printer.cfg: load bed mesh by material, PLA/PETG profiles from new PEI bed
    [printer.cfg]
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2026-04-06 betthaj-label: mirror text for bed-side readability on textured PEI
    [betthaj-label.scad]
2026-04-06 printer.cfg: improve purge line speed and adhesion
    [printer.cfg]
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2026-04-06 betthaj-label: Mango text
    [betthaj-label.scad]
2026-04-07 remove tracked generated files (already in .gitignore)
    [microscope-adapter.stl]
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2026-05-12 Add DIN rail PCB mount model (32x72mm)
    [dinrailmount-pcb-32x72.scad, dinrailmountmulti.scad]
2026-06-07 model improvemtents
    [washer-m3-3mm.scad]
2026-10-09 docs: warn about OrcaSlicer rotate behavior; add support interface settings
    - Document critical OrcaSlicer --rotate-x/y pitfall: doesn't place model on bed
    after rotation, causing floating models and excess supports
    - Add support interface settings to slice.sh for better supported surface quality
    (top_z_distance, interface_layers, interface_spacing, interface_speed)
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
